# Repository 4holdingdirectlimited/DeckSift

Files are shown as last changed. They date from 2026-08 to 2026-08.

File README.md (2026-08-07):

# DeckSift

A TCG card scanner and physical sorter that runs **entirely on your own machine** — no hosted services, no logins, no cloud. A webcam identifies cards via on-device AI embeddings, a rule engine decides which bin each card belongs in, and an Arduino-driven feeder and servo mechanism physically routes the card there.

DeckSift is a fork of [MAULT](https://mault.xyz) by [dishwasher-detergent](https://github.com/dishwasher-detergent/mault). The v1 machine's Fusion 3D design, build photos, and firmware base come from the original project (MIT — full credit in [Credits](#credits)); DeckSift adds a fully-local, single-user software stack, firmware hardening, and a revised print kit (`card_sorter_decksift.3mf` — same parts, organized for faster, more efficient printing).

**License:** free for personal use. Commercial use (selling DeckSift or building it into a product) requires a license from 4holdingdirectlimited — see [LICENSE](LICENSE). The MAULT-derived portions remain MIT. See [Credits](#credits).

## MakerWorld

Original hardware build: https://makerworld.com/en/models/3066180-tcg-card-sorting-machine#profileId-3451252

## How it works

1. A feeder mechanism (continuous-rotation servo + roller) pulls a card from the hopper into view of the webcam, into a fixed, per-camera-calibrated scan region (see the calibration screen)
2. The browser crops that region to a straightened card image (plain Canvas 2D, no computer vision needed, since the camera mounting and card size are fixed and calibrated ahead of time)
3. The image is sent to the server for embedding search (SigLIP, running locally on CPU or DirectML GPU)
4. PostgreSQL vector similarity search (pgvector) identifies the card
5. Configurable, per-collection bin rules — plus bundle, set-chase, wishlist, and value routing — decide which bin the card should go to
6. The web app sends a serial command to the Arduino, which drives the trapdoor/paddle/pusher servos to route the card into that bin

## Features

- **Fully local & offline** — Postgres, the API, the web app, the vision model, and card art all run on this machine. No accounts, no hosted database, no cloud calls at scan time. Only the one-time card-data sync needs the internet.
- **Live webcam scanning** with automatic card detection and identification; captures wait for the card to physically settle at the sensor before the shot is taken
- **Multi-TCG support**: pluggable card-search adapters per game — MTG/Scryfall, Yu-Gi-Oh!, Digimon, Gundam Card Game, Pokémon, Disney Lorcana, One Piece, Star Wars: Unlimited, Union Arena, Flesh and Blood, and Pokémon TCG Pocket (11 games) — each with its own field definitions driving sorting, filtering, and bin rules; a config-driven architecture makes adding more games a small, independent task (see `custom/TCGS_ROADMAP.md`)
- **Rule-based sort bins**, grouped by collection, with and/or rule trees across each game's own card fields (color, rarity, price, set, type line, mana value, …)
- **Value-based binning** — numeric price rules on every bin (`Price (USD) greater than 2` → reject bin, etc.), backed by live prices for MTG and Yu-Gi-Oh!
- **Bundle mode** — assemble fixed-composition bundles (e.g. 15 common / 15 uncommon / 5 rare / 5 mythic) with no duplicates, optional holo filtering, live running value, and pause-on-complete. Every run gets an inventory **SKU** (`MTG-40-001`), stores the full list of cards it contained, and can be exported as a CSV record
- **Set-chase mode** — route every card from a target set that you don't already own into a chase bin, automatically building set-complete piles
- **Wishlist routing** — specific cards (by id or name pattern) route to their own bin ahead of normal rules
- **Holo/foil detection** — two-frame scan light (firmware-controlled LED) + heuristic classifier, with a smart skip so matte cards only need one frame
- **Misprint / error-card flagging** — every scan shows a match-accuracy %; cards whose art differs noticeably from the catalog (shifted colors, extra features) get an amber "possible misprint" flag so valuable error cards don't sail through silently
- **Sound bin-full logic** — per-bin status vs physical capacity, per-bin Empty/reset, and pause-on-overflow so a bin can never silently overflow
- **Collection tools** — export everything scanned as CSV (including a **TCGplayer-compatible inventory CSV** for the seller portal), a duplicate report, a set-completeness view, and a card library browser with set/rarity filters
- **Digitize mode** — bulk-record a library without sorting: every scanned card is saved to the collection while cards route to the catch-all bin
- **Orientation tolerance** — cards fed upside-down are auto-rotated before matching, so alignment is relaxed
- **Card grid** sorting (by name, price, rarity, etc.) adapts automatically to whichever game a collection uses
- **Remote monitoring** — watch an in-progress scan session live from another device on your LAN
- **Discord notifications** (optional) for sorter errors/jams
- **Feeder, servo, camera, and scan-light diagnostics** — live calibration tools plus hardware tests from the browser, so servos and lights are verified before a run
- **In-app hardware build guide** (`/build`) with bill of materials, wiring diagrams, and assembly instructions

## Stack

| Layer | What | Version |
| --- | --- | --- |
| Web | React + Vite + React Router + Tailwind CSS + TanStack Query | React 19 · Vite 6 · Tailwind 4 |
| Server | Hono + Drizzle ORM + PostgreSQL (pgvector) | Hono 4 · Drizzle 0.45 · Postgres 18.4 |
| Vision | SigLIP base (patch16-512) via `@huggingface/transformers`, onnxruntime-node (CPU q8 or DirectML GPU fp32) | transformers 3.8 |
| Auth | **none** — fully-local single-user build, no logins | — |
| Hardware | ESP32-S3 (primary) or Arduino Uno R4 Minima via Web Serial (9600 baud) — the same sketch also builds for RP2040/Pico + STM32 (see `arduino/main/CONTROLLERS.md`), PCA9685 servo driver, IR sensors, scan-light LED | — |
| Monorepo | Turborepo + pnpm workspaces | pnpm 9 |

**Security posture (2026-08):** `pnpm audit` reports **0 critical** and **0
high-severity issues in the runtime dependency graph**. The one remaining
runtime-path flag is a React Router advisory that only affects **RSC mode**
(server actions) — this app is a classic client-rendered SPA, so it does not
apply; the fix is v8-only and upgrading would be a breaking change with no
benefit here. All other `pnpm audit` findings are transitive dependencies of
dev-only tooling (the `shadcn` CLI, `tsup`, ESLint) that is never shipped or
exposed. The app itself is local-only and unauthenticated by design — it is
not intended to be exposed to the public internet.

## Project structure

```
packages/
├── shared/   @magic-vault/shared - types, constants, evaluate-bin rule engine
├── server/   @magic-vault/server - Hono API, Drizzle schema/db, card-search adapters, sync jobs
└── web/      @magic-vault/web    - React SPA (scanner, bins, collections, library, admin, build guide)
arduino/      Firmware + build docs (arduino/main/main.ino, BUILD.md, SERIAL_PROTOCOL.md)
3d model/     Printable enclosure/module design (Fusion 360 + .3mf)
custom/       Our docs: CHANGES.md (all modifications), SETUP.md (local runbook), TCGS.md, PLAN.md, HARDWARE_V2.md, PRODUCT.md
drizzle/      Generated SQL migrations
scripts/      Local helpers: start-server.cmd, start-web.cmd, local-db.mjs, backup-db.mjs,
              arduino-compile.sh
              (+ packages/server/scripts: seed-local.ts, apply-bin-capacities.ts, import-cardset.ts, bench-vectorize.ts)
```

## Getting started

**Prerequisites:** Windows (or Linux/macOS with adjustments), [pnpm 9](https://pnpm.io), Node 20.6+ (the run scripts use `--env-file`), and a portable PostgreSQL + pgvector install (see below). The browser must support the [Web Serial API](https://developer.mozilla.org/en-US/docs/Web/API/Web_Serial_API) (Chrome/Edge) for hardware control.

```bash
pnpm install
cp .env.example .env   # then fill in DATABASE_URL etc.
```

### 1. Local PostgreSQL (no Docker/admin needed)

Download the portable PostgreSQL + pgvector bundle (user-space, no admin rights or services required):

```bash
curl -L -o postgres.zip \
  https://github.com/YukeonWayne/pg_pgvector_binary/releases/download/v18.4-pgvector0.8.3-win32-x64/postgres-18.4-pgvector-0.8.3-win32-x64.zip
```

Extract it to `<workspace>/.local/postgres` (the helper scripts look there —
`<workspace>` is the folder *containing* your clone, e.g. `C:\Users\you`
when you cloned to `C:\Users\you\decksift`; override with `DECKSIFT_LOCAL_DIR`
if you'd rather keep local state inside the repo), then initialize and start:

```bash
PGBIN="<workspace>/.local/postgres/win32-x64/bin"
"$PGBIN/initdb" -D "<workspace>/.local/postgres/data" -U postgres -A trust -E UTF8 --locale=C
# Start detached (Windows):
powershell -NoProfile -Command "Start-Process -FilePath '<workspace>\.local\postgres\win32-x64\bin\postgres.exe' -ArgumentList '\"-D\" \"<workspace>\.local\postgres\data\" \"-p\" \"5433\" \"-c\" \"listen_addresses=127.0.0.1\" \"-c\" \"shared_buffers=1GB\"' -WindowStyle Hidden"
```

(`node scripts/local-db.mjs start` replaces the manual Start-Process line once
Postgres is set up — it launches the server with the same settings.)

Create the database and apply the local bootstrap (creates the pgvector extension, the RLS role, and the `auth_is_org_member()` function). Run it **before** `db:migrate` and **again after**:

```bash
"$PGBIN/psql" -h 127.0.0.1 -p 5433 -U postgres -c "CREATE DATABASE mault;"
"$PGBIN/psql" -h 127.0.0.1 -p 5433 -U postgres -d mault -f packages/server/sql/local-bootstrap.sql
pnpm --filter @magic-vault/server db:migrate
"$PGBIN/psql" -h 127.0.0.1 -p 5433 -U postgres -d mault -f packages/server/sql/local-bootstrap.sql
```

Then point `.env` at it:

```
DATABASE_URL=postgres://postgres@127.0.0.1:5433/mault
VECTORIZE_DEVICE=dml    # or cpu (see .env.example)
```

A helper script manages the server day-to-day, and can register a no-admin logon auto-start:

```bash
node scripts/local-db.mjs start|stop|status|install|uninstall
```

Back up the database with one command (safety net — see `scripts/backup-db.mjs`):

```bash
node scripts/backup-db.mjs backup        # dump to .local/backups
node scripts/backup-db.mjs list          # list existing backups
node scripts/backup-db.mjs restore <file>  # restore (wipes current data)
```

### 2. Seed + run

```bash
# One-time seed: games, default collection, bin set, default bundle config
cd packages/server && npx tsx --env-file ../../.env scripts/seed-local.ts

# Start the stack (two detached processes) — from the repo root:
powershell Start-Process -FilePath ".\scripts\start-server.cmd" -WindowStyle Hidden
powershell Start-Process -FilePath ".\scripts\start-web.cmd" -WindowStyle Hidden
```

Open **https://decksift.local:5173** (preferred) or **http://localhost:5173** — no login, it opens straight to the scanner.

**decksift.local** is the friendly hostname: run `node scripts/ssl-setup.mjs`
once to generate a locally-trusted HTTPS certificate (required because Web
Serial only works in a secure context), then add this line to your hosts file
(as admin):

```
127.0.0.1  decksift.local
```

Restart the web server afterwards. `localhost` keeps working as a fallback,
and the app is also reachable from other devices on your LAN via `http://<pc-ip>:5173`.

### 3. Card sync (the one internet step)

In the web app, go to **Admin → Sync** and run the sync for each game you'll use. The first MTG sync downloads the Scryfall catalog (~54k cards) and embeds each with the local SigLIP model — roughly 9–10 hours on a mid-range GPU, one-time and resumable (it skips cards already embedded, and the catalog is cached on disk). Syncs are queued one game at a time and auto-advance; the sync paces itself so your desktop stays responsive and scans keep priority.

> Until sync completes for a game, scanning can't match anything — the `cards` table is empty and the search has nothing to compare against.

### 4. Flash the firmware + calibrate

1. Flash `arduino/main/main.ino` — the **ESP32-S3 is the primary board**
   (native-USB Web Serial, optional Wi-Fi/WebSocket/OTA). Libraries:
   **ArduinoJson**, **Adafruit PWM Servo Driver**, and **WebSockets** (ESP32
   build only). See `arduino/main/WIRING_S3.md` for the DevKitC-1 wiring and
   `arduino/main/README.md` for the Tools-menu settings (Uno R4 / RP2040 /
   STM32 equivalents in `arduino/main/CONTROLLERS.md`).
2. Open **http://localhost:5173**, connect the board via **Web Serial**, then
   calibrate at `/app/calibrate` (drag the scan region, tune servo positions)
   and run the hardware diagnostics to verify servos and the scan light.
3. Load cards, connect the camera (see [Webcam](#webcam)), and scan.

**Full walkthrough, hardware BOM, wiring, and tuning:** see `custom/SETUP.md` (our local runbook) and `arduino/main/BUILD.md`.

## Environment variables

Copy `.env.example` to `.env` and fill in. All variables live in a single root `.env` (Vite reads up from `packages/web`).

| Variable | Purpose | Default |
| --- | --- | --- |
| `DATABASE_URL` | Local Postgres connection string | `postgres://postgres@127.0.0.1:5433/mault` |
| `PORT` | API port | `3001` |
| `WEB_URL` | CORS origin / absolute links (Discord) | `http://localhost:5173` |
| `VITE_API_URL` | Base URL of the API (baked into the web bundle). **Leave empty** for same-origin — the Vite dev/preview server proxies `/api` to the API, so any hostname (localhost, decksift.local, LAN IP) works | *(empty — relative)* |
| `VITE_APP_ENV` | `local` / `development` / `qa` (banner + warnings) | `local` |
| `VECTORIZE_DEVICE` | `cpu` (q8) or `dml` (DirectML GPU, fp32 — ~1.9× faster) | `cpu` |
| `SYNC_FETCH_BATCH` | Parallel image fetches during sync | `16` |
| `SYNC_EMBED_BATCH` | GPU embedding batch (8 is proven stable on weaker GPUs) | `8` |
| `SYNC_PACE_SCAN_MS` | Sync back-off per batch while a scan is active | `200` |
| `SYNC_PACE_IDLE_MS` | Sync beat per batch when idle | `10` |
| `ART_CACHE_DIR` / `SYNC_CACHE_DIR` | Override local cache locations | `<repo>/packages/server/.cache/…` |

## Database

Migrations live in `drizzle/`:

```bash
pnpm --filter @magic-vault/server db:generate  # generate a migration from schema changes
pnpm --filter @magic-vault/server db:migrate   # apply migrations
pnpm --filter @magic-vault/server db:push      # push schema directly (dev)
pnpm --filter @magic-vault/server db:studio    # open Drizzle Studio
```

The migration history is a single regenerated baseline from the current schema — all tables use org-scoped RLS policies (defense-in-depth for any future deployment; the local build enforces isolation at the route layer). Postgres starts with `shared_buffers=1GB` so the card catalog + vector index stay resident in RAM.

### What still needs the internet

- **Card data sync** (Scryfall / Yu-Gi-Oh! / Digimon / Gundam / Pokémon) in the Admin page — how the card database gets built
- **Card art** — the image proxy fetches new art; everything synced is disk-cached locally afterwards
- **One-time SigLIP model download** — the vision model downloads once from HuggingFace, then all scanning runs fully on-device
- **Discord webhooks** — optional, only if you configure a URL

Everything else — scanning, sorting, calibration, the database, and vision — runs entirely on the local machine.

## Hardware

The full bill of materials, wiring diagrams, and assembly instructions live in the app at `/build`. In short:

- **Controller** — ESP32-S3 (DeckSift's primary: native-USB Web Serial, more headroom) or the original Arduino Uno R4 Minima, both driving a PCA9685 servo controller over I2C. The same firmware builds for RP2040/Pico and STM32 — see [arduino/main/CONTROLLERS.md](arduino/main/CONTROLLERS.md) for per-board wiring, logic levels, and support status.
- 9 positional SG90 servos (3 per module: trapdoor, paddle gate, pusher) plus 1 continuous-rotation SG90 for the feeder
- IR sensors for card-feed detection (hopper + one per module)
- **Scan light** (LED 1, PCA9685 channel 0) — a small angled LED the firmware toggles for two-frame holo detection
- External 5 V PSU (4–10 A) into the PCA9685 `V+`, common ground with the controller (mandatory)
- Enclosure and module parts are in `3d model/` (Fusion 360 source + printable `.3mf`)

Upload `arduino/main/main.ino` (libraries: ArduinoJson, Adafruit PWM Servo Driver, WebSockets for the ESP32 build). It communicates via JSON over USB serial (9600 baud): the web app sends `{"bin": N}` and the Arduino runs the routing sequence. Protocol details in `arduino/main/SERIAL_PROTOCOL.md`.

## Webcam

Primary: **EMEET C60E 4K** — the higher resolution gives holo detection and the embeddings more detail to work with. Recommended settings:

- Autofocus: Off (fixed focus on the scan plane)
- Resolution: 1080p or 4K, whichever the scan-region calibration covers
- Brightness / contrast / saturation: moderate, consistent lighting

The original build used a Logitech C920 (Auto Focus: Off · Focus: 50% · Auto Exposure: On · Low Light Compensation: On · Auto White Balance: On · Brightness: 140 · Contrast: 140 · Saturation: 160 · Sharpness: 130).

## Documentation

- `custom/SETUP.md` — **the local runbook**: stack URLs, start/stop, first-run setup, bundle/chase/wishlist modes, bin capacities, value sorting, machine responsiveness tuning
- `custom/CHANGES.md` — every modification relative to upstream, in revert order
- `custom/TCGS.md` — multi-TCG architecture, top-20 TCG data-source status, adding a new game
- `custom/PLAN.md` — firmware roadmap (non-blocking state machine, pipelining, watchdog) and the machine-build commissioning checklist
- `arduino/main/BUILD.md` — hardware build guide, wiring, calibration
- `arduino/main/SERIAL_PROTOCOL.md` — JSON serial contract

## Credits

**Original machine design — MAULT by dishwasher-detergent (Kenneth Bass).** The
v1 card sorter's Fusion 3D design (`3d model/Card Sorter.f3d` / `card_sorter.3mf`),
the build photos, the parts list, and the Arduino firmware base all come from the
original [MAULT](https://mault.xyz) project, released under the MIT License. The
original is the sorter we built from, and it stays credited in the app footers,
the `/build` guide, and this file.

**3D model files** (`3d model/`) are licensed separately under
**CC BY-NC-SA 4.0** by Kenneth Bass — see `3d model/LICENSE`. The software in
this repository is licensed under the DeckSift License (personal use free,
commercial by license).

**DeckSift work — 4holdingdirectlimited.** Everything else: the fully-local
software stack (no hosted services, no logins, on-device vision, local card
storage), the firmware modifications (command-id correlation, jam detection,
watchdog timing, EEPROM calibration, scan light), and the revised print kit
(`3d model/card_sorter_decksift.3mf` — same machine, organized for faster,
more efficient printing). The full change log is in `custom/CHANGES.md`.

**License.** DeckSift is free for personal use; commercial use is by license from
4holdingdirectlimited (see [LICENSE](LICENSE)). The MAULT-derived portions
remain MIT-licensed under the original notice included in the LICENSE file.

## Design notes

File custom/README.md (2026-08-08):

# Custom

This folder is the home for **our** modifications to DeckSift — everything
that makes this build different from the upstream MAULT project. The upstream
project is tracked as the `upstream` git remote (`dishwasher-detergent/mault`);
all of our work lives on the `custom` branch (the repo default).

## How this project is organized

```
custom/                  <- this folder: our docs (CHANGES, SETUP, TCGS, PLAN)
arduino/main/main.ino    <- the firmware we modify IN PLACE (tracked by git on `custom`)
arduino/main/*.md        <- build/setup docs (also ours, tracked on `custom`)
```

**Important:** do not keep a second copy of `main.ino` in here. The firmware is
edited in place at `arduino/main/main.ino` — git on the `custom` branch is the
change tracker. This folder is for documentation and anything that doesn't
belong next to the sketch.

## Docs in this folder

| File | What it is |
| --- | --- |
| `CHANGES.md` | **Every modification vs upstream**, cumulative, in revert order (currently items 1–73) |
| `SETUP.md` | The local runbook: stack URLs, start/stop, first-run setup, bundle/chase/wishlist modes, bin capacities, value sorting, sync pacing |
| `TCGS.md` | Multi-TCG architecture, top-20 TCG data-source status, adding a new game |
| `PLAN.md` | Firmware roadmap (state machine, pipelining, watchdogs) + machine-build commissioning checklist |
| `HARDWARE_V2.md` | Production-leaning hardware review: materials/manufacturing, stability/mass, mechanism hardening, and the 3-machine/1-PC multi-machine plan |
| `PRODUCT.md` | Product strategy (v1 home → v2 commercial), adoption drivers, and the value-vs-effort feature backlog |

## Git workflow

- `custom` — the only active branch (also the GitHub default). All DeckSift
  work lives here.
- `upstream` — a read-only remote pointing at `dishwasher-detergent/mault`;
  `git fetch upstream` then `git merge upstream/master` (or selective
  file-level integration — see `CHANGES.md` Item 50) brings in anything new.
- **Keeping the fork banner tidy:** when GitHub shows "N commits behind"
  (upstream advanced), record their history without adopting their code:
  `git merge -s ours upstream/master -m "Sync with upstream history"` then
  push. Behind drops to 0; none of upstream's file content changes (their
  useful changes are still integrated selectively per `CHANGES.md`).
- There is no `master` branch in this repo — the pre-rename work line that
  briefly lived there was fully superseded by `custom` and deleted.

## Status

All modifications are documented in `CHANGES.md` (items 1–73). The headline
deliverables, all on the `custom` branch:

- **Fully local, no logins** — removed hosted Neon, Supabase-style auth, and
  better-auth; single-user local build with a portable local PostgreSQL
  (item 12–13)
- **Local-first everything** — disk-cached card art + sync catalogs (item 14,
  37), local card hydration (item 15), on-device SigLIP with optional DirectML
  GPU acceleration (item 16)
- **Multi-TCG** — config-driven adapters for MTG, Yu-Gi-Oh!, Digimon, Gundam,
  Pokémon + dataset importer for no-API games (item 19–20, 23, 27)
- **Seller/collector features** — value-based binning (21), bundle mode with
  holo/duplicate toggles + value (24, 29, 31), per-bin capacity + bin status
  (7, 30), set-chase mode (35), wishlist routing (36), export CSV / duplicates /
  set completeness (32–34)
- **Holo detection** — two-frame scan light + heuristic classifier (17–18),
  needs threshold calibration on the real rig (`PLAN.md`)
- **Firmware** — command-id ACK correlation, jam detection on all modules,
  boot recovery, EEPROM calibration persistence, stage-1 watchdog
  (1, 4–6, 10); full non-blocking state machine + interrupt-driven IR
  feeding delivered (49); pipeline feed (start next card while the
  previous one is still routing) still planned (`PLAN.md`)
- **Tooling & CI** — typecheck, firmware compile, CI checks (2)

Machine-specific operational details live in `SETUP.md`.

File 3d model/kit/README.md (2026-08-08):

# DeckSift Bambu Lab print kit

A quantity kit for the printable side of the machine, organized for faster,
more efficient Bambu Studio print batches (fewer color/material changes,
better bed utilization). The geometry is **identical** to the original parts —
this kit only reorganizes them.

## Files

| File | What it is |
| --- | --- |
| `QUANTITY_SHEET.md` | One machine's printable parts as a tick-box checklist, with filament/settings notes |
| `PLATES.md` | The 16-plate print plan for `card_sorter_decksift.3mf` |

## The 3MFs

- `3d model/card_sorter.3mf` — the original design (dishwasher-detergent),
  mesh, slicer-ready.
- `3d model/card_sorter_decksift.3mf` — DeckSift's revised parts file,
  print-optimized: **30 unique objects across 16 plates** (plate previews are
  embedded as `Metadata/plate_N.png`). Use this one with this kit.

Both files are the same machine — pick whichever matches your print setup.
3D files are CC BY-NC-SA 4.0 (`3d model/LICENSE`); full credit to the
original designer (see repo README Credits).

## Workflow

1. Open `card_sorter_decksift.3mf` in Bambu Studio.
2. Walk the 16 plates in order; tick the functional groups in
   `QUANTITY_SHEET.md` as you print.
3. Assemble per `arduino/main/BUILD.md` (structural → servos → sensors →
   wiring → firmware → calibrate).

## Notes

- The 3MF objects are unnamed meshes — the sheet groups parts by machine
  role, so keep the plate preview open while printing.
- PLA for housings; PETG if warm. 0.2 mm layers, 15–20 % infill (solid where
  the preview shows pads).

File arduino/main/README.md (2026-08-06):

# DeckSift — Arduino firmware & build docs (`arduino/main`)

This folder contains the firmware and build documentation for the **DeckSift TCG card sorter** — a hopper-fed, Arduino-driven machine that physically routes scanned trading cards into one of seven bins.

| File | Purpose |
| --- | --- |
| `main.ino` | The firmware — **one universal sketch** that runs on several boards (see below). |
| `board-config.h` | Board abstraction: EEPROM init/commit, I2C pins, interrupt attach, IR pin defaults. |
| `BOM.txt` | **Printable shopping list** — every part, screw, and tool with quantities. |
| `CONTROLLERS.md` | Per-board wiring, logic levels, power, and honest support status. |
| `WIRING_S3.md` | **Pin-by-pin ESP32-S3 DevKitC-1 wiring guide** (header layout, PCA9685, IR, LEDs, power). |
| `BUILD.md` | Complete build guide: bill of materials, wiring, assembly, first power-on, calibration. |
| `SERIAL_PROTOCOL.md` | JSON command/response reference for talking to the firmware over USB serial (and Wi-Fi). |

> Upstream source (the machine's original design): [github.com/dishwasher-detergent/mault](https://github.com/dishwasher-detergent/mault) · interactive build guide: [mault.xyz/build](https://mault.xyz/build) · 3D models: `3d model/Card Sorter.f3d` (Fusion 360) and `3d model/card_sorter.3mf` (slicer-ready) in the upstream repo. The firmware here is DeckSift's modified version of that base.

## What the machine does

A hopper feeds cards one at a time through three stacked routing modules. Each module can drop a card into one of two side bins (via a paddle gate and pusher) or pass it down to the next module (via a bottom trapdoor). Bin 7 is a catch-all with all three trapdoors open:

| Module | Bins |
| --- | --- |
| Module 1 | Bin 1, Bin 2 |
| Module 2 | Bin 3, Bin 4 |
| Module 3 | Bin 5, Bin 6 |
| (catch-all) | Bin 7 |

Each module has **3 positional SG90 servos** (bottom trapdoor, paddle gate, pusher) plus an **IR sensor**; a **continuous-rotation SG90** runs the feeder. All servos are driven by one **PCA9685** over I²C. The web app sends `{"bin": N}` over USB serial and the Arduino runs the full routing sequence.

## Supported boards (universal firmware)

One sketch, several controllers — `board-config.h` hides the small
differences (EEPROM emulation, I2C pins, interrupt attach), so you just pick
the board in the Arduino IDE / PlatformIO and flash:

| Board | Status | Notes |
| --- | --- | --- |
| **ESP32-S3** | ✅ Compiles + flashing docs; ⚠️ wiring not yet commissioned | DeckSift's primary going forward. Flashing settings below; wiring/power/logic-level guide in `CONTROLLERS.md`. |
| **Arduino Uno R4 Minima** | ✅ Reference build (compiles + wired) | The original controller; real EEPROM. |
| **RP2040 / Pico** | ✅ Compiles (3 % flash); ❌ not commissioned | Flash-emulated EEPROM (`EEPROM.begin`). See `CONTROLLERS.md` before wiring. |
| **STM32** | ✅ Compiles (GenF4); ❌ not commissioned | Flash-emulated EEPROM. See `CONTROLLERS.md` before wiring. |
| **Classic Uno/Nano** | ⚠️ Too little RAM | Sketch needs ~6 KB SRAM; the ATmega328P has 2 KB. |

> ⚠️ **Compiling ≠ supported.** Until a board has been wired and fully
> calibrated, treat it as experimental — the sketch is portable, but the
> machine wiring is only proven on the Uno R4. Read **`CONTROLLERS.md`**
> (logic levels, pins, power) before building a non-Uno machine.

## Flashing the firmware

1. Install the **Arduino IDE** (or arduino-cli).
2. Install the required libraries via **Library Manager**:
   - **ArduinoJson**
   - **Adafruit PWM Servo Driver** (also pulls in Adafruit BusIO)
   - **WebSockets** (only needed to compile the ESP32 build — used for the
     Wi-Fi/WebSocket transport + OTA; other boards ignore it)
3. Select your board + COM port (settings below), open and upload `main.ino`.
4. Open the **Serial Monitor at 9600 baud** — after the board resets you should see:

   ```json
   {"status":"ready"}
   ```

5. In the web app, connect the controller via **Web Serial**, then calibrate at `/app/calibrate` (see `BUILD.md` → Calibrate from the app).

### ESP32-S3 — recommended Tools menu settings

Web Serial needs the board to expose a serial port the browser can see. The
correct setting depends on which of the two USB paths your board has:

| Board type | USB CDC On Boot | Upload Mode | Notes |
| --- | --- | --- | --- |
| **With a USB-serial bridge (CH340/CH343/CP2102) — the common dev board** | **Disabled (default)** | **UART0 / Hardware CDC (default)** | `Serial` maps to UART0 through the bridge; flash and Web Serial both use that port. This is what was verified on a CH343 dev board. |
| **Native USB only** (no bridge chip) | **Enabled** | UART0 / Hardware CDC | `Serial` maps to the native USB port. |

Other recommended settings for both:

| Setting | Value | Why |
| --- | --- | --- |
| Board | **ESP32S3 Dev Module** | Generic S3 board |
| Flash Size | **16 MB** (if your module has it) or **8 MB** | Match your module — the 4 MB default scheme already has dual 1.25 MB OTA app slots, so extra flash only buys bigger SPIFFS, not OTA headroom |
| Partition Scheme | **Default 4 MB with spiffs** | The ESP32 build is ~1 MB (76% of the 1.25 MB app slot) — keep a scheme with **dual OTA slots** (this one is OTA-verified). Avoid "no OTA"/minimal schemes |
| CPU Frequency | **240 MHz** | Default |
| I2C pins | GPIO **8** (SDA) / **9** (SCL) | PCA9685 bus — override with `-DI2C_SDA=n` if your wiring differs |
| Upload Speed | **921600** | Faster flashing |

Equivalent `platformio.ini` (PlatformIO — drop the `USB_CDC_ON_BOOT` flag on
a bridge-equipped board, keep it for native-USB-only boards):

```ini
[env:esp32s3]
platform = espressif32
board = esp32-s3-devkitc-1
framework = arduino
build_flags =
  ; -DARDUINO_USB_CDC_ON_BOOT=1   # only for native-USB-only boards
  -DI2C_SDA=8
  -DI2C_SCL=9
monitor_speed = 9600
```

> Uno R4 / RP2040 / STM32 need no special settings — Web Serial works via
their built-in USB serial.

### ESP32-S3 — Wi-Fi, WebSocket & OTA (optional)

The ESP32 build can join your Wi-Fi network so the browser talks to the board
over the LAN and the Arduino IDE pushes updates over the network:

1. Flash the firmware over USB as above, then connect in the web app
   (**Connect Device**) and open **Calibrate → Wi-Fi & OTA**.
2. Enter your network SSID + password and hit **Save & Connect**. The board
   stores them in EEPROM and joins the network; it announces its IP
   (`{"status":"wifi","ip":…}`) which the panel auto-fills.
3. Click **Connect** next to the board address — the browser now drives the
   machine over Wi-Fi (`ws://decksift-board.local:81`), so the USB data cable
   can be unplugged (keep USB for power, or power from the 5 V PSU rail).
4. OTA: in the Arduino IDE, select the board's network port
   (**Sketch → Upload Using a Network Port**). The orange comms LED lights
   while a network flash runs.

> **arduino-cli on Windows:** `arduino-cli upload -p <ip> …` fails with
> “No response from device” until you allow `espota.exe` through Windows
> Firewall (inbound TCP — the device connects back to the tool mid-flash).
> The Arduino IDE already has this rule; run once as admin:
> `New-NetFirewallRule -DisplayName "ESP32 OTA (espota)" -Direction Inbound -Action Allow -Program "$env:LOCALAPPDATA\Arduino15\packages\esp32\hardware\esp32\<core>\tools\espota.exe" -Profile Any`

Multi-rig setups: change `WIFI_HOSTNAME` in `main.ino` per board (e.g.
`decksift-board-2`) so they don't collide on mDNS. See `SERIAL_PROTOCOL.md`
for the Wi-Fi commands.

## Quick test after first power-on

With the external servo supply connected, send over serial:

```json
{"test": true}
```

This cycles every bottom and paddle open, sweeps all pushers left then right, resets to neutral, briefly spins the feeder, and replies `{"status":"test_complete"}`.

## Pin and channel summary (full details in `BUILD.md`)

- **IR sensors** (active-LOW, internal pull-up): Module 1 gate → `D2`, Module 2 gate → `D3`, Module 3 gate → `D4`, Hopper throat → `D5`
- **PCA9685** I²C to Arduino `SDA`/`SCL`, logic `VCC` → `5V`, `GND` → `GND`
- **PCA9685 channels**: `0` = LED 1 (scan light), `1` = LED 2 (green, operating), `2` = LED 3 (red, fault), `3` = LED 4 (orange, comms fault), `4–6` = Module 1 (bottom, paddle, pusher), `7–9` = Module 2, `10–12` = Module 3, `13` = Feeder, `14–15` spare
- **Servo power**: external 5 V PSU (4–10 A) into PCA9685 `V+`, with the PSU ground tied to **both** PCA9685 `GND` and Arduino `GND` (common ground is mandatory)

## Webcam

Primary: **EMEET C60E 4K** — the higher resolution gives holo detection and
the embeddings more detail to work with. Recommended: autofocus off (fixed
focus on the scan plane), 1080p or 4K capture, moderate and consistent
lighting.

The original build used a Logitech C920 (Auto Focus: Off · Focus: 50% · Auto
Exposure: On · Low Light Compensation: On · Auto White Balance: On ·
Brightness: 140 · Contrast: 140 · Saturation: 160 · Sharpness: 130).

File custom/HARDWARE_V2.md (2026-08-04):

# Hardware v2 — production-leaning review & multi-machine plan

This document reviews the physical sorter as it stands and lays out a v2 path
toward **small-scale production**: a sturdier, faster, more reliable machine,
and — long term — running **three machines + three cameras off one computer**,
concurrently, instead of building one bigger machine.

Current machine (v1) baseline, from `arduino/main/BUILD.md`:

- 3 stacked routing modules × 3 **SG90** servos (trapdoor, paddle, pusher) + 1
  continuous-rotation SG90 feeder — all on one PCA9685
- 4 reflective IR sensors (hopper throat + one per module gate), polled in
  firmware
- PLA/PETG printed structure, M2/M3 screws into plastic, 5 V 4–10 A PSU
- Routing delays: card-enter 300 ms · paddle 300 ms · push 600 ms (~3 s/card)

Companion docs: `PLAN.md` (firmware roadmap — non-blocking state machine,
interrupt feeding, watchdogs, the v2 servo/detection notes) and this page's
"Software" section for multi-machine support.

---

## 1. Material & manufacturing — from one-off prints to production

### 1.1 Material choice per part

PLA is fine for a hobby prototype but wrong for production: it creeps under
constant servo load, softens in a warm room (a card sorter near a window or a
laptop exhaust is plenty), and is brittle at the thin bosses around servo
screws. What to use instead:

| Material | Creep | Heat | Toughness | Print ease | Verdict for us |
| --- | --- | --- | --- | --- | --- |
| PLA | poor | poor (~55 °C) | brittle | easiest | keep for prototype only |
| PETG | ok | ok (~80 °C) | good | easy (no enclosure needed) | **minimum viable production material** |
| ABS | ok | good (~100 °C) | good | needs enclosed printer + fumes | good for housings; overkill on ease |
| ASA | ok | good | good | like ABS, UV-stable | best drop-in for ABS without the UV worry |
| Nylon / PA-CF | great | great | very tough | hard (drying, warping) | only for wear parts / arms |
| Injection mold | best | — | — | one-time tooling cost | the real production step (see 1.3) |

**Recommended v2 material map:**
- **Module housings + base:** ASA (or PETG if no enclosed printer). ASA prints
  like ABS, resists heat/creep/UV, and stays dimensionally stable under servo
  loads.
- **Pusher arms, flapper linkages, feeder roller core:** PETG or nylon — these
  take the most force.
- **Bearing/shaft bosses:** design in seats for brass heat-set inserts and
  press-fit bearings rather than printing the hole itself (see §3).
- **Print settings for production parts:** ≥4 perimeters, ≥40 % infill
  (gyroid), 0.2 mm layer height, **anneal PETG/ASA** after printing (bed- or
  oven-based) to relieve layer stress and improve interlayer strength.

### 1.2 Fasteners & assembly quality

The v1 BOM is 22× M3 + 33× M2 self-tapping into plastic. That's the classic
field-failure point — screws strip on the second rebuild.

- **Heat-set brass inserts (M2/M3)** in every screw boss the firmware touches
  (servo mounts, module stacking, base panels). Machines get torn down for
  calibration/jams; threaded inserts survive it.
- **Thread-locker** (blue Loctite) on servo-horn screws and any M3 that holds
  a moving part.
- **Cable management as a first-class feature:** a v2 base has a cable
  channel per module and a single connector (e.g. 2× IDC or a small
  Molex/Phoenix connector) per module so a module can be swapped in the field
  without re-wiring 10 servos. This is the difference between "one-off" and
  "serviceable in production".

### 1.3 Real production: injection molding

If we ever run, say, 10+ units, the **module housing is the part to mold**
(one housing × 3 per machine = high volume, moderately complex, consistent
dimensions beat every printed part). The base plate can stay laser-cut sheet
metal. Rule of thumb: injection molding starts to win when you need ≥ several
hundred of a part and the design is frozen. Until then, ASA/PETG printing +
brass inserts is the pragmatic step.

---

## 2. Stability & mass — the free throughput upgrade

A light PLA machine **shakes** at the moment a servo slams a pusher across.
That vibration does three bad things at higher speed: IR sensors get false
edges, the camera image blurs/rolls during the capture window, and card
settling takes longer because the stack is still ringing. A stable base fixes
all three — it's the cheapest way to shorten `DELAY_*` times.

**v2 stability plan:**
- **Mass under the machine, not on it:** a 6 mm laser-cut steel base plate
  (≈300×300 mm ≈ **4 kg**) or a paving-slab/plywood sandwich bolted to the
  printed base. Target ≥3–4 kg of dead weight below the modules.
- **Sorbothane / soft-silicone feet** (not hard rubber) under the plate, sized
  for the mass — decouples the machine from the desk and damps servo
  transients. Hard feet just pass the vibration through.
- **One rigid spine:** bolt the 3 modules to a single aluminum backplate
  (3–4 mm) instead of stacking each module on the plastic of the one below.
  Eliminates cumulative flex, keeps the card path straight, and keeps the
  camera mount rigid.
- **Lower the center of gravity:** put the PSU and Arduino under the base
  plate, not beside the machine.
- **Camera mount on the machine, not the desk:** a rigid arm off the
  backplate keeps the scan region fixed relative to the card plane; vibration
  is then common-mode (card and camera move together) and the capture stays
  sharp.

**Result:** with the mass + damping in place, `DELAY_CARD_ENTER` and the
settle times can be measured and shortened safely — the machine stops shaking
before the card does.

---

## 3. Mechanism hardening (the parts that wear)

- **Servos → MG90S** (metal gears, ~2.2 kg·cm): survives sustained pushing,
  pin-compatible (see `PLAN.md` v2 section for current draw/capacitance
  notes). For the pusher specifically, consider a metal-gear **MG996R**-class
  servo if the arm needs more authority — only where measured torque demands
  it, since they draw ~1 A each.
- **Bearings, not plastic-on-plastic:** the paddle linkage and pusher arm
  pivot on printed holes today. v2 seats **brass bushings or 623/624
  ball bearings** in those pivots. Result: consistent motion, no
  print-tolerance binding, and no hole-wear over thousands of cycles.
- **Metal pin through the flappers:** the shared paddle linkage is a
  screw-in-plastic joint; v2 uses a steel dowel pin + bearings so both
  flappers track evenly for the machine's lifetime.
- **Feeder (the real throughput bottleneck):** the G20 o-ring roller works but
  slips and double-feeds on glossy cards.
  - v2: a **silicone pinch roller** with an adjustable gap (two rollers, one
    driven) — precise single-card separation, better on foils.
  - Add a small **hopper agitator** (a servo wiggle or vibrator) so cards
    don't bridge at the throat.
  - An **encoder on the feeder** (slotted wheel + IR pair) measures feed
    distance — stop position becomes sensor-confirmed, and a second card
    feeding is detectable (encoder keeps moving while the beam is still
    broken).
- **Card path:** radiused guides, anti-static brushes at the hopper (foil
  cards + dry air = static cling), and a replaceable wear strip where the
  pusher face contacts cards.

### Sleeve tolerance (v2 design decision)

v2 should sort **sleeved cards** (a store's inventory lives in sleeves; Roca's
Sifter already reads them). Every tolerance that currently assumes a bare
0.3 mm card needs a sleeved variant:

- **Bin capacity halves:** a premium sleeve ≈ 0.4 mm + the 0.3 mm card ≈
  **0.7 mm** total. The shared constants now expose
  `CARD_THICKNESS_SLEEVED_MM = 0.7` / `computeBinCapacity(bin, thickness)`, so
the app can flip capacities without new code — the machine must physically
accept ~half the cards per bin (or the bins get deeper).
- **Feed path:** feeder gap, pinch-roller spacing, hopper throat and guide
  widths all open up ~0.4 mm; the o-ring/silicone roller contact patch needs
  to grip the sleeve without slipping (sleeves are slicker than card stock).
- **Module clearances:** card-path height and the trapdoor/paddle gaps must
  pass a sleeved card (bulkier, slightly stiffer).
- **IR detection:** sleeve gloss can double-reflect the beam; re-aim or
  dim the sensors (a comparator front-end helps — see PLAN.md).
- **Foil detection on sleeved cards:** the sleeve is glossy and adds its own
  reflections, so the two-frame holo difference signal needs recalibration
  (light angle, thresholds) against real sleeved captures — this is
  calibration work on the rig, not a code change.
- **Orientation:** sleeved cards feed the same way; the orientation-tolerant
  crop (implemented in the web app) is sleeve-agnostic.

Software is already ready: `computeBinCapacity(bin, thickness)` + the
sleeved constant mean the capacity model switches with one value; the
remaining work is mechanical (gaps) and calibration (foil thresholds).
- **Card path:** radiused guides, anti-static brushes at the hopper (foil
  cards + dry air = static cling), and a replaceable wear strip where the
  pusher face contacts cards.

---

## 4. Sensing & control for production reliability

Recap + production additions on top of `PLAN.md`:

1. **Interrupt-driven IR edges** (both `PLAN.md` and v2) — no polling, no
   missed edges; lets the feeder run continuously.
2. **Comparator front-end** (LM393) on the IR sensors — clean digital edges,
   immune to the sensor's analog transition zone.
3. **Confirm motion by sensor, not timer** — every phase completes on an edge
   or a watchdog budget, never on a fixed blind delay. This is what makes
   "faster" also mean "safer".
4. **Jam/EOF feedback:** module gate sensors already exist; wire the hopper
   sensor to also flag "empty hopper" to the operator (it does today) and add
   a **card-confirmed-at-bin** check where cheap (a fifth sensor per module
   isn't needed — the gate sensor + pusher position is enough).
5. **E-stop + cover interlock** for unattended production runs — a hard stop
   that also tells the app "machine halted, clear me".

---

## 5. Multi-machine: 3 machines, 1 computer

Long-term goal: sync + run **three machines and three cameras off the same
PC**, concurrently, sharing one card library — instead of a bigger single
machine.

### 5.1 Physical / electrical

| Concern | v1 (1 machine) | v2 (3 machines) |
| --- | --- | --- |
| USB | 1× serial + 1× camera | **Powered USB 3 hub**; 3× serial (Web Serial supports multiple ports) + 3× cameras |
| Camera bandwidth | 4K single | 3× **1080p MJPEG** (~4K over USB on three UVC cameras saturates the bus and starves the GPU-adjacent pipelines). 1080p is ample for card ID + holo |
| Servo power | 1× 5 V 4–10 A | **Per-machine 5 V PSU** (fault isolation; one dead rail doesn't take down the farm). 30+ MG90S servos across 3 rails |
| Control | 1× Uno R4 | 1× Uno R4 per machine — each is a self-contained sorter brain; the PC is the orchestrator |
| Vision | 1× EMEET C60E | 1× camera per machine on a rigid arm; per-machine scan-region calibration |

### 5.2 Software architecture (the real work)

Today the app assumes one machine: a single serial provider, a single camera,
a single active bundle run, org-scoped bins/scans. Multi-machine needs a
**station** concept:

- **`station_id` on the machine-facing entities** — scans, bin status, bundle
  runs (bundle **configs stay shared**: all machines can run the same
  recipe). Physical bins are per-machine; the card library, collections, and
  rules are shared.
- **One server, per-station state:** scan uploads carry `stationId`; the
  routing pipeline (`use-scanned-cards.tsx`) becomes a per-station instance —
  3 serial providers, 3 cameras, 3 bin-status strips, 3 bundle runs. A
  station switcher in the UI (or a 3-column "farm" layout on one screen).
- **The GPU is the shared bottleneck — and it's fine:** one SigLIP session
  embeds serially at ~0.4 s/card (DirectML). 3 machines at 2 s/card need
  ~1.5 embeds/s — under the ~2.5/s the single model sustains, so one GPU
  serves all three. Embeddings just queue; the sync's scan-aware pacing
  already keeps the desktop usable.
- **DB:** add `station_id` to scans + bundle runs (nullable — single-machine
  installs unaffected). No new tables otherwise.
- **Networking:** everything stays local (USB), no changes to sync/library.

### 5.3 Throughput math

| Config | Per-card | Per machine / hr | Farm / hr | 8-h shift |
| --- | --- | --- | --- | --- |
| v1 (current) | ~3 s | ~1,200 | 3× = 3,600 | ~29k |
| v2 (interrupt feed + MG90S + pipelined) | ~1.7 s | ~2,100 | 3× = 6,300 | ~50k |
| v2 with shorter bins (3-bin configs) | ~1.4 s | ~2,500 | 3× = 7,500 | ~60k |

So a 3-machine v2 farm sorts a **100,000-card backlog in ~2 shifts** — that's
small-scale production territory (a local game store's bulk buy-in, a
collection liquidation, etc.) without a conveyor-belt machine.

---

## 7. vs commercial machines (the Roca question)

*“Could three upgraded units perform like a ~$25–30k Roca?”* — now we can
answer it with real numbers, because TCGplayer publishes the specs:

| Machine | Cost | Capacity | Throughput | Notes |
| --- | --- | --- | --- | --- |
| **Roca Sorter** | ~$25k | 1,000-card batch | **Sort 500/hr · Sift 725/hr** | Alphabetizes + digitizes; ~2 h per 1,000-card batch; over 50 programmed sorts; **Yu-Gi-Oh! needs a separate machine** (different card size) |
| Roca Sorter Max | ~$40k | 3,000-card run | Sort 300/hr · Sift 450/hr | Same, bigger batch |
| Roca Sifter | ~$2–3k | single/stream | **1,800/hr sift** | Compact add-on: reads cards **in premium sleeves**, separates foil/non-foil, any orientation; designed to feed the Sorter |

### The headline: we're already faster on raw sorting

| Config | Cards/hr (sort) | vs Roca Sorter |
| --- | --- | --- |
| Our v1 (current, ~3 s/card) | **~1,200** | **2.4×** |
| Our v2 (one machine, ~1.7 s/card) | **~2,100** | **4.2×** |
| Our 3× v2 farm | **~6,300** | **~12.6×** |

**So on raw “put these cards in those bins” throughput, one of our v1 machines
already beats the $25k Roca Sorter, and the farm is an order of magnitude
ahead.** Roca's price buys *other* capabilities, not speed. Where Roca genuinely
wins:

1. **Alphabetizing & full inventory ordering** — Roca sorts a batch into a
   complete, sell-ready order (we route to 7 bins).
2. **Digitization + TCGplayer integration** — every card read to a database
   and listable in one workflow (we record scans, but don't list).
3. **Sleeved-card handling** (Sifter) — reads cards *in premium sleeves*; we
   require unsleeved cards.
4. **Foil sifting at scale** — Sifter's foil separation is industry-proven; our
   holo detection is still in calibration.
5. **Unattended batch runs** — load 1,000, walk away for 2 h. Ours wants a
   hopper re-load and bin-empty roughly every ~500–1,500 cards.
6. **Orientation tolerance** — Roca reads cards in any orientation; our scan
   region expects a fixed orientation (feeder-straightened).
7. **Service/warranty + dedicated support.**

And where **we** win beyond cost:

- **One machine, all games** — Roca requires a *separate $25k unit* for YGO;
  our single unit handles MTG/YGO/Pokémon/Digimon/Gundam (and any added TCG)
  by changing the collection.
- **Cost:** ~$1k/machine → ~$3–5k for the 3-machine farm vs $25–75k of Roca
  hardware (Sorter + Max + Sifter + YGO unit).
- **No subscriptions or lock-in** — Roca sells a Software & Service Plan;
  ours is local and free forever.
- **Directed sorting tools Roca lacks:** bundle mode (Roca has “Pack Creator”,
  comparable), set-chase, wishlist routing, per-card value rules, per-bin
  capacity management.

### What to borrow from Roca (the “similar tools” worth copying)

- **Sleeve-tolerant feeding** — a feeder that handles sleeved cards would let
  us sort inventory without unsleeving. Big workflow win for a store.
- **Orientation-tolerant reading** — relax the scan-region constraint (or add
  a rotation-tolerant crop) so cards needn't be perfectly aligned.
- **Foil sift as a first-class mode** — a dedicated “foil / non-foil” sift
  pass (our two-frame holo detection, run as a pure sift) mirrors the Sifter.
- **Batch digitization** — a “digitize this hopper” mode that scans + records
  every card without sorting (feeds the library + collection DB).

### Honest verdict

For **bins, bundles, chase sets, and value/rule sorting**, three of our
machines beat a $25k Roca on throughput by ~10× and on cost by ~5–10×. What
Roca buys that we don't have is *complete inventory digitization +
alphabetization + sleeved-card handling + unattended autonomy* — those are
feature gaps, not speed gaps, and the top two (sleeve feed, digitize mode)
are on the v2 ideas list above.

### The measurement gate (do this before believing any of the above)

All of section 7 assumes the current machine is tuned and *measured*. Before
spending on v2/multi-machine:

1. Finish the v1 firmware (state machine + interrupt feeding — `PLAN.md`).
2. Run the first machine on real card stock and record **cards/hour, error
   rate, jams per 1,000 cards, and double-feed rate**. These four numbers are
   the baseline every upgrade is judged against (and the honest test of the
   1,200/hr claim above).
3. Try the cheapest upgrades first (stability base, feeder tweaks) and
   re-measure — only spend on MG90S/bearings/encoders where the baseline says
   the bottleneck actually is.
4. Only then decide the farm: the numbers will tell you if 3 machines buy you
   the Roca-class throughput at 1/10 the cost — or where the gaps make it not
   worth it for your actual workloads.

---

## 8. Phased roadmap (revised)

Priority order is deliberate: **software first, then tune the single machine,
measure it, and only then spend on v2/farm hardware.**

- **Phase 0 — finish v1 firmware + current software** (from `PLAN.md`):
  non-blocking state machine, interrupt feeding, watchdogs, plus any remaining
  app work. Nothing else happens until the first machine runs the whole
  scan → route → bin pipeline reliably.
- **Phase 1 — build + tune the first machine:** assemble it, calibrate,
  then run the **measurement gate** (§7): cards/hour, error rate, jams and
  double-feeds per 1,000. Fix what the numbers say is broken (feeder first —
  it is almost always the bottleneck). Re-measure after every change.
- **Phase 2 — cheap upgrades, measured:** stability base + sorbothane feet,
  feeder tweaks — the low-cost changes that shorten the blind routing delays.
  Re-measure. Only the bottlenecks that survive this get the expensive
  treatment (MG90S, bearings, comparator/encoder) in Phase 3.
- **Phase 3 — v2 prototype (one machine):** the hardened parts from §1–§4
  (ASA/PETG + brass inserts, bearings, pinch roller, encoder, comparator).
  Target **~1.7–2 s/card** sustained. Re-measure against the Phase 2 numbers;
  if the upgrade didn't move the metric, don't replicate it three times.
- **Phase 4 — station software:** `station_id` plumbing, per-station scanner
  islands, 3 serial + 3 cameras on one PC; verify one GPU serves 3 machines.
- **Phase 5 — the farm:** 3 machines running concurrently (build the third
  machine only if Phase 3's numbers justify it), injection-molded housings if
  volume is real, daily ops routine (hopper load, bin empty, per-machine CSV
  export).

Each phase is independently shippable; Phases 0, 2 and 4 are mostly software
or cheap, and every hardware decision is gated on a measured number rather
than enthusiasm.

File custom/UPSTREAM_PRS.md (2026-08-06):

# Upstream pull requests — status & ready-to-paste descriptions

Three firmware PRs back to the original project
(`dishwasher-detergent/mault`). All are **open, rebased onto the latest
upstream master, and MERGEABLE**. All three use **LED 1 (ch0) as the scan
light** — no spare-channel LED 5 wiring — and upstream's own master has since
moved to LED 1 too, so the PRs align with the maintainer's direction.

| PR | Branch | Status |
| --- | --- | --- |
| [#4](https://github.com/dishwasher-detergent/mault/pull/4) | `pr/fw-robustness` | OPEN · MERGEABLE |
| [#5](https://github.com/dishwasher-detergent/mault/pull/5) | `pr/fw-config` | OPEN · MERGEABLE · title updated to "scan light (LED 1)" |
| [#6](https://github.com/dishwasher-detergent/mault/pull/6) | `pr/fw-state-machine` | OPEN · MERGEABLE |

Each branch was rebased onto `upstream/master` (61c67e7) with our exact
firmware content, so each PR's diff is a clean reviewable change set.

The full PR bodies (for updates or re-opening) live in:

- `custom/upstream-pr-1.md` — PR #4 (fw-robustness)
- `custom/upstream-pr-2.md` — PR #5 (fw-config)
- `custom/upstream-pr-3.md` — PR #6 (fw-state-machine)

---

## PR 1 — `pr/fw-robustness`

Harden firmware: id-correlated replies, fixed serial buffer, all-module jam
watch, boot recovery. Body: `custom/upstream-pr-1.md`.

## PR 2 — `pr/fw-config`

Persist servo calibration to EEPROM and add a scan light (LED 1). Supersedes
the earlier "scan light (LED 5)" version — the scan light moved to LED 1/ch0
to keep the wiring on existing hardware. Body: `custom/upstream-pr-2.md`.

## PR 3 — `pr/fw-state-machine`

Rebuild firmware as a non-blocking state machine with interrupt-driven
feeding. Includes the robustness fixes and the config persistence + scan
light from the sibling PRs, so this branch is the complete modern firmware.
Body: `custom/upstream-pr-3.md`.

---

## Opening with `gh` (once authenticated)

```bash
gh pr create --repo dishwasher-detergent/mault \
  --head 4holdingdirectlimited:pr/fw-robustness --base master \
  --title "Harden firmware: id-correlated replies, fixed serial buffer, all-module jam watch, boot recovery" \
  --body-file custom/upstream-pr-1.md

gh pr create --repo dishwasher-detergent/mault \
  --head 4holdingdirectlimited:pr/fw-config --base master \
  --title "Persist servo calibration to EEPROM and add a scan light (LED 1)" \
  --body-file custom/upstream-pr-2.md

gh pr create --repo dishwasher-detergent/mault \
  --head 4holdingdirectlimited:pr/fw-state-machine --base master \
  --title "Rebuild firmware as a non-blocking state machine with interrupt-driven feeding" \
  --body-file custom/upstream-pr-3.md
```

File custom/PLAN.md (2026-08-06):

# Plan — faster + more robust card sorter (Arduino Uno R4 Minima)

> **Status: historical roadmap.** Everything under "Where the current firmware
> falls short" is shipped — the firmware is now a non-blocking state machine
> with EEPROM calibration, interrupt-driven IR and Wi-Fi/WebSocket/OTA (see
> `custom/CHANGES.md` items 49–59). Kept as the record of the v1 plan and the
> still-open physical commissioning checklist below.

Goal: keep the existing Arduino hardware and make the machine **faster** (higher
throughput, less dead time between cards) and **more robust** (no silent hangs,
no lost calibration, recovers from jams/timeouts cleanly).

All line references are to `arduino/main/main.ino` as of upstream `a1dfa44`
(unchanged in our copy). This is a draft roadmap — pick items per priority; each
is independently implementable.

## Where the current firmware falls short

### 1. Blocking, delay-heavy sequence — ~~the #1 bottleneck and robustness issue~~ ✅ rebuilt

`routeCard()` and `runFeeder()` used to block `loop()` for the entire feed +
routing sequence. They're now a **non-blocking state machine** (`runMachine()` in
`main.ino`): every mechanical phase advances on a timestamp or a sensor edge,
so serial stays responsive mid-operation. `{"cancel": true}` aborts any phase
back to neutral, jam alerts abort immediately, and commands arriving mid-run
get a clean `{"error":"busy"}` instead of being silently delayed.

### 2. Polled IR instead of edge detection — ~~leaves speed on the table~~ ✅ rebuilt

Module 1's IR sensor is now **interrupt-driven** (`attachInterrupt` on
`IR_PIN_MODULE1`): the feeder stops the instant the beam is crossed, and the
motor runs **continuously** (no pulse/pause cycling — the old
`pulseDuration`/`pauseDuration` feed cycling is gone). Module 2/3 sensors stay
polled, which is fine for routing waits.

### 3. Calibration is RAM-only — lost on every reboot ✅ built

`{"setConfig": ...}` and `{"setFeederConfig": ...}` write only to RAM
(`moduleConfig` L64–68, `feederConfig` L80). Re-powering the unit reverts to
stock pulses, so a tuned machine must be re-calibrated after every power cycle.

**Plan:** persist `moduleConfig` + `feederConfig` to EEPROM (Uno R4 Minima has
8 KB). Load on boot in `setup()` (L580–595), add `{"saveConfig": true}` /
`{"resetConfig": true}` commands.

### 4. `String` + line buffer — slow drift toward heap fragmentation

`String inputBuffer` (L87) plus `String` use in `handleCommand` fragment the
heap over long sessions. On an always-on sorter this eventually causes weird
crashes.

**Plan:** replace with a fixed `char` buffer + index, and avoid `String`
construction in the parser. (`ArduinoJson`'s `JsonDocument` is fine.)

### 5. Serial framing is fragile

Commands are newline-delimited with a 256-char cap that **silently discards**
the whole line on overflow (L597–611), and a truncated line is just ignored.
No CRC, no ACK contract, so a dropped byte = silently lost command mid-run.

**Plan:** keep newline framing but respond to every command (already done for
known commands — add explicit ACK for every path), and drop oversized lines
with an `{"error":"line too long"}` instead of silence. Optionally add a
start-of-command marker (e.g. `>` prefix) so partial garbage can be flushed.

### 6. Jam/error coverage is module-1-only, idle-only

The jam watch covers only module 1 and only between commands.

**Plan:** generalize `checkModule1Jam()` to all modules and the hopper, and run
the watch from the state machine even mid-sequence. Report `{"error":"jam","module":N}`
per module with per-module timeout config.

### 7. No per-phase watchdog

`waitForCard()` (L49–56) and the feeder have timeouts, but a stalled servo or a
stuck paddle during a *motion* phase blocks forever (e.g. the 600 ms `DELAY_PUSH`
is fixed, but a physically jammed pusher isn't detected).

**Plan:** every state in the machine gets a budget; exceeding it returns to
neutral and reports an error. Consider an MCU-level watchdog reset as a last
resort (R4 Minima: software watchdog via the Renesas core is limited — a
loop-level supervisor is the practical option).

## Speed items (independent of robustness)

- **Concurrent motions** — start opening the next module's bottom while the
  current pusher retracts (currently strictly sequential).
- **Re-tune timing with real measurements** — `DELAY_CARD_ENTER` 300 /
  `DELAY_PADDLE` 300 / `DELAY_PUSH` 600 ms and feeder pulse 80 / pause 50 /
  settle 150 ms are starting points, not optimized. Measure actual fall/push
  times and shrink safely.
- **Pipeline feed** — with the state machine, the feeder can start pulling the
  next card while the previous card is still being pushed, bounded by sensor
  state rather than fixed delays.
- *(Optional)* raise serial to 115200 baud — commands are small so 9600 is not
  the bottleneck, but telemetry/status streaming would benefit. **Note:** the
  web app hardcodes 9600 in `packages/web/src/features/scanner/api/use-serial.tsx`,
  so baud changes must be coordinated there.

## Power / electrical robustness (hardware side)

- Bulk capacitance on the servo rail (e.g. 1000–2200 µF) to absorb SG90/MG90S
  inrush — cheap insurance against brownouts that corrupt an in-flight sequence.
- Verify common ground between PSU, PCA9685 and Arduino (already called out in
  `arduino/main/BUILD.md`).
- Consider a soft-start for the feeder (ramp pulse instead of slam to full speed).

## Revised Bambu Lab print kit (planned)

DeckSift's own contribution to the *printable* side of the v1 machine: a
Bambu Lab quantity kit that reorganizes the original parts (same geometry,
from `3d model/`) into faster, more efficient print batches — fewer
color/material changes and better bed utilization. Not yet in the repo; the
original `Card Sorter.f3d` / `card_sorter.3mf` files remain the canonical
parts, with full credit to the original designer (see `README.md` Credits).

- [ ] Produce the quantity sheet + reorganized plate layout for Bambu Studio
- [ ] Add the kit files under `3d model/` alongside the originals
- [ ] Wire the kit into the `/build` guide and `arduino/main/BUILD.md`

## Suggested order of work

1. ~~Fixed serial buffer + oversized-line error (5)~~ ✅
2. ~~EEPROM persistence for calibration (3)~~ ✅
3. ~~Non-blocking state machine (1)~~ ✅
4. ~~Interrupt-driven IR feeding (2)~~ ✅ — the throughput win
5. Watchdog budgets per phase (7), full jam coverage (6) — partially done (whole-op watchdog + jam abort exist; per-phase budgets are implicit in each phase's timeout)
6. Concurrent/pipelined motions — last, once the machine is deterministic

## Machine build commissioning checklist

For when the physical sorter is assembled. Verify each link independently before
end-to-end tuning so a timing problem isn't mistaken for a vision or routing
problem. Software pre-reqs are noted inline.

1. **Camera / vision** (EMEET C60E 4K replacing the Logitech):
   - 4K stream at the capture crop; contour/perspective warp clean on a real
     card in the rig; no glare zone.
   - Time one full scan in the browser (capture → embed → match → UI). Compare
     with `pnpm bench:vectorize` (~380 ms DML on this machine).
   - RTX 3080 later: `VECTORIZE_DEVICE=dml` already works on NVIDIA; optional
     fp16 dtype; re-run the bench to confirm.
2. **Firmware timing** (measure, don't guess):
   - Actual feed time (hopper → module 1 IR) at the configured feeder speed.
   - Stopwatch each bin's sort path, then shrink `DELAY_*` constants safely.
   - Tune feeder speed/settle; verify no double-feed (two cards tripping IR).
3. **Pipeline** (the 2 s/card target):
   - Confirm the current serial flow is feed → scan → sort with NO overlap
     (verified in code, ~2.9–3.5 s/card) and time it on hardware.
   - Then implement the non-blocking state machine + pipeline feed (next card
     fed + scanned while the previous is being sorted). Target per-card
     ≈ scan + sort ≈ 1.7–2.2 s on shallow bins.
4. **Bundle workflow** (software now built — `custom/SETUP.md`):
   - 4-rarity bundle on bins 1–4 (or any rarity/bin mapping you set in the
     Bundle Mode panel); counts reach targets; duplicates → reject bin;
     bundle-complete pause; resume after restart. Remaining work is purely
     physical: verify the reject bin (catch-all bin 7) is where you expect and
     that bin routing lines up with the machine.
5. **Holo detection** (classifier thresholds need calibration):
   - The two-frame scan light is built (firmware LED 1 / PCA9685 ch0,
     smart skip if clearly matte). Wire the LED (see BUILD.md) and calibrate
     `FOIL_SECOND_FRAME_THRESHOLD` / `FOIL_DIFF_THRESHOLD` on real captures.
   - Collect labeled scans (manual foil toggle) during early runs; train the
     embedding classifier; verify on DBZ/One Piece foils — foil is a different
     product ID there, so detection feeds card identity, not just a badge.

## Related docs

- `custom/TCGS.md` — top-20 TCG plan, data-source status, adding games.
- `arduino/main/SERIAL_PROTOCOL.md` — current JSON contract (will grow: cancel, save/reset config, per-module jam timeouts).
- `arduino/main/BUILD.md` — wiring/BOM notes (PSU, capacitance, scan light).

## v2 machine — faster & more accurate sorting

> Full production review (materials, mass/stability, mechanism hardening,
> multi-machine architecture): **`HARDWARE_V2.md`**. The section below is the
> machine-level summary.

Ideas for a second build (or a major refit of this one). Goals: shorter
per-card time, fewer stripped parts, and sensor-confirmed motion instead of
blind timing.

### Servo upgrade: SG90 → MG90S

- **Why** — SG90 plastic gears strip under sustained pushing (the #1 field
  failure). MG90S has **metal gears + ~2.2 kg·cm torque** (vs ~1.8) at similar
  speed (~0.1 s/60°), so routes stay fast and repeatable for much longer.
- **Wiring** — pin-compatible drop-in (same PWM, 4.8–6 V). The higher stall
  current (~700 mA vs ~250 mA each) needs the servo rail's bulk capacitance
  bumped (2200 µF, see Power notes above) and the 5 V PSU sized for peak
  current, not steady state.
- **Consider also** — the R4 Minima's timers can drive up to ~12 servos
  natively; dropping the PCA9685 for direct timer PWM removes a driver stage
  and lets each servo run at its own calibration. (Keep PCA9685 for the LEDs
  + scan light.) Only worth it if the state-machine timing demands tighter
  control than the PCA9685's 1.6 kHz update gives.

### Card detection: faster, more reliable

Current: IR through-beam sensors polled every ~5 ms inside `interruptibleDelay`
while the feeder pulses — the card is only caught when a poll happens to see it,
and a full `delay()` cycle can be missed. Options for v2, best-first:

1. **Interrupt-driven edges** — `attachInterrupt` on the module-1 + hopper
   sensors (both already on interrupt-capable pins D2–D5). Stop the feeder the
   instant the beam is crossed; no polling, no missed edges. This is the
   single biggest speed win (feeder can run continuously instead of pulsed).
2. **Comparator front-end** — a Schmitt-trigger/op-amp stage (e.g. LM393)
   turns the analog sensor into a clean digital edge, eliminating the slow
   analog-transition zone where a card can sit half-detected. Cheap, bulletproof.
3. **Optical encoder on the feeder roller** — a slotted wheel + IR pair
   measures actual feed distance, so “card at module 1” is confirmed by
   distance *and* beam, not a fixed pulse time. Enables precise stop position
   and double-feed detection (encoder continues moving while the beam is
   already broken).
4. **Camera as feedback** — the scan camera already sees the card; a motion
   check in the capture region can confirm “arrived + settled” without extra
   hardware. Useful as a cross-check, not a primary sensor (slower loop).

### What stays (already in the roadmap above)

- Non-blocking state machine (section 1) — prerequisite for interrupt feeding.
- Per-phase watchdog budgets (section 7) — with faster motion, a missed edge
  must still abort safely.
- Pipelined feed (Speed items) — next card feeds while the previous routes.

### Target

With interrupt feeding + MG90S + pipelining: **~1.5–2 s/card** on shallow
bins (vs the current ~3 s baseline) with sensor-confirmed, jam-safe motion.

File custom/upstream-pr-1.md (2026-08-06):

## Why
The machine can lose a card to a silent failure: a dropped serial byte
mid-route, a jam nobody notices, or a power blip that leaves a card sitting
in the mechanism. Each of these previously just hung or dropped the command.

## What changed
- **Id-correlated replies** — every command may carry an optional `id`; all
  replies echo it, so the host can match responses even while asynchronous
  messages (jam alerts) arrive in between. No more mistaking one reply for
  another.
- **Fixed-size serial buffer** — the `String` accumulator is replaced by a
  fixed `char` buffer; oversized lines are discarded with a clean
  `{"error":"line too long"}` instead of silently truncating.
- **Jam watch on all modules** — a card sitting at any module gate for longer
  than the timeout (no routing command in flight) reports `{"error":"jam"}`,
  not just module 1.
- **Boot recovery report** — if the board boots with a card already at a
  gate (power loss mid-run), it reports `{"error":"recovered","module":N}` so
  the operator flushes the device before feeding.

## Testing
1. Flash to an Uno R4 Minima (libraries: ArduinoJson, Adafruit PWM Servo Driver).
2. Send `{"test":true,"id":1}` — the reply echoes `"id":1`.
3. Hold a card at a module gate for the jam timeout — expect `{"error":"jam","module":N}`.
4. Send an oversized line — expect `{"error":"line too long"}`.

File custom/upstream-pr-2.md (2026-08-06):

## Why
Calibration was RAM-only: every reboot reverted a tuned machine to stock
pulses. Also, holo/foil detection needs a second, differently-lit capture —
the build guide's "spare" channel 14 LED was never wired by anyone.

## What changed
- **EEPROM calibration persistence** — `{"setConfig":...}` and
  `{"setFeederConfig":...}` save to EEPROM automatically; `{"saveConfig":true}`
  persists explicitly; `{"resetConfig":true}` restores factory defaults. A
  magic/version guard ignores stale data from older firmware.
- **Scan light on LED 1 (ch0)** — the holo-detection light now uses the
  on-board LED 1 channel instead of spare channel 14: `{"led":1,"on":true}`.
  Wiring stays on the existing PCB, no spare-channel cable. (LEDs 2-4 on
  ch1-3 remain free as indicator lamps.)
- Safe defaults while uncalibrated: module pulses are all within a few µs of
  each other so a freshly-flashed board cannot over-travel and strip a gear.

## Testing
1. Flash, then `{"setConfig":{"module":1,"bottomClosed":150,...}}`.
2. Reboot — the tuned values survive (`{"readConfig":true}` or observe motion).
3. `{"led":1,"on":true}` lights LED 1 on ch0.

> Note: this branch supersedes the earlier "scan light (LED 5)" version —
> the scan light moved to LED 1/ch0 to keep the wiring on existing hardware.

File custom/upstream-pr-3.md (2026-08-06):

## Why
Feed/route/test/clear were blocking `delay()` sequences: serial froze for
the whole operation, so a jam mid-route was invisible until it timed out,
and the feeder could only pulse (polling IR) instead of running continuously.

## What changed
This is the firmware rework the other two PRs build toward — it includes the
robustness fixes (id-correlated replies, fixed serial buffer, jam watch) and
the config persistence + scan light from the sibling PRs, so this branch is
the complete modern firmware.

- **Non-blocking state machine** — every operation is a phase machine driven
  from `loop()`: `{"cancel":true}` aborts any phase to neutral, jam alerts
  abort immediately, commands arriving mid-run get a clean `{"error":"busy"}`,
  and a whole-operation watchdog replaces per-command deadlines.
- **Interrupt-driven module-1 IR** — the feeder stops the instant the beam is
  crossed (`attachInterrupt`), so the motor runs continuously instead of
  pulse/pause cycling. This is the biggest single throughput win.
- **Scan light on LED 1 (ch0)** for two-frame holo detection.

## Testing
1. Flash; confirm `{"status":"ready"}`.
2. `{"bin":1}` — watch the route run while `{"ping":true}` still answers
   mid-route.
3. Send `{"cancel":true}` mid-route — returns to neutral cleanly.
4. Feed: the feeder runs continuously and stops the moment the card reaches
   module 1's sensor.
5. Hold a card at a gate — jam alert aborts any active operation.

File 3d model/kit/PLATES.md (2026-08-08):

# Print plates — `card_sorter_decksift.3mf` (16 plates)

The DeckSift print-optimized 3MF lays the machine's **30 parts** across **16
plates**. Each plate's preview is embedded in the file as
`Metadata/plate_N.png` (also `plate_N_small.png`); the per-plate contents
below are a guide, not a substitute for the preview — Bambu Studio shows the
exact arrangement.

| Plate | Likely contents (verify against preview) |
| --- | --- |
| 1 | Enclosure / base halves |
| 2 | Base + base panels |
| 3 | Module 1 housing parts |
| 4 | Module 1 flappers + pusher arm |
| 5 | Module 2 housing parts |
| 6 | Module 2 flappers + pusher arm |
| 7 | Module 3 housing parts |
| 8 | Module 3 flappers + pusher arm |
| 9 | Bin bases 1–4 |
| 10 | Bin bases 5–7 + bin catches |
| 11 | Hopper tube + wall |
| 12 | Feeder roller + mounts |
| 13 | IR sensor mounts + small brackets |
| 14 | Wire channels / zip-tie guides |
| 15 | Lid / top pieces |
| 16 | Remaining small parts / spares |

Print in plate order (structural first, per BUILD.md). If a plate looks
under-filled, group it with an adjacent plate manually — the kit favors
correct grouping over strict plate count.

Total check: **30 objects**, each on exactly one plate. If your Bambu Studio
version shows a different split, use the preview as the source of truth.

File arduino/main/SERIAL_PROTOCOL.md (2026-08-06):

# Serial protocol — `main.ino`

The firmware communicates over USB serial at **9600 baud**, one JSON object per line. The web app uses the Web Serial API; anything can talk to it (Serial Monitor, scripts, etc.).

On ESP32-S3 boards the same protocol is also served over a **WebSocket on port 81** when Wi-Fi is configured (see [Wi-Fi / WebSocket transport](#wi-fi--websocket-transport-esp32-s3-only) below) — both transports speak the same JSON, so the web app can drive the machine over USB or Wi-Fi interchangeably.

**Frame format:** newline- (`\n` or `\r`) terminated JSON. Lines longer than 256 characters are discarded.

## Wi-Fi / WebSocket transport (ESP32-S3 only)

The ESP32 firmware build can join your LAN and serve the identical JSON protocol over a WebSocket:

- **Configure once:** send `{"wifi":{"ssid":"…","password":"…"}}` (usually over USB on first setup). The credentials are stored in EEPROM and the board joins the network on every boot.
- **Address:** the board registers mDNS as `decksift-board.local` and listens for WebSockets on **port 81** — `ws://decksift-board.local:81` (use the IP if mDNS isn't available). Change `WIFI_HOSTNAME` in the sketch per machine for multi-rig setups.
- **Handshake:** when a WebSocket client connects, the firmware sends the same `{"status":"ready","proto":2}` boot line it sends on USB reset, so the web app's connect flow (ready → protocol check → mechanical test) is identical on both transports.
- **Replies:** every line the firmware emits (command replies, boot ready, async jam alerts) goes to USB serial **and** is broadcast to any connected WebSocket client. Id-correlated replies keep the two transports unambiguous.
- **OTA:** with Wi-Fi configured, the Arduino IDE can flash updates over the network (Sketch → Upload Using a Network Port). The orange comms LED is lit during an OTA update.
- **Not breaking USB:** boards without Wi-Fi (Uno R4, Pico, STM32) compile without this section; the USB flow is unchanged.

## Command ids (request/response correlation)

Every command may carry an optional numeric `"id"` field. When present, the firmware echoes it on **every reply to that command**:

```json
{"bin": 3, "id": 17}
{"status":"routed","bin":3,"id":17}
```

The web app uses this to correlate responses to requests instead of assuming "the next line is the answer". Messages that are **not** replies to a command — the boot `{"status":"ready"}` line and asynchronous `{"error":"jam",...}` alerts — never carry an id, so they can never be mistaken for a command's response.

Commands without an `id` are answered without one (backward compatible).

## Boot

On reset the board replies with its status and the protocol version (used by
the web app to detect app/firmware mismatches):

```json
{"status":"ready","proto":2}
```

## Commands

### Route a card

```json
{"bin": 1}
```

Runs the full feed + routing sequence. `bin` must be 1–7:

| Bin | Route |
| --- | --- |
| 1 | Module 1: open paddle, push **left** |
| 2 | Module 1: open paddle, push **right** |
| 3 | Module 1 bottom open → Module 2, push **left** |
| 4 | Module 1 bottom open → Module 2, push **right** |
| 5 | M1 → M2 → Module 3, push **left** |
| 6 | M1 → M2 → Module 3, push **right** |
| 7 | All bottoms open (catch-all) |

On success:

```json
{"status":"routed","bin":1}
```

On failure (hopper empty / timeout), an error is emitted and all servos return to neutral:

```json
{"error":"empty: feeder hopper is out of cards","empty":true}
{"error":"timeout: feeder did not deliver card to module 1","empty":false}
{"error":"timeout: no card detected at module 2"}
{"error":"timeout: no card detected at module 3"}
```

### Mechanical test

```json
{"test": true}
```

Opens every bottom and paddle, sweeps all pushers left then right, resets to neutral, spins the feeder ~500 ms, cycles the 4 LED channels. Replies:

```json
{"status":"test_complete"}
```

### Liveness check

```json
{"ping": true}
```

Replies immediately — the web app uses this as a heartbeat to detect a hung
or unresponsive board within seconds:

```json
{"status":"pong"}
```

### Reset to neutral

```json
{"neutral": true}
```

```json
{"status":"ok"}
```

### Flush the device

```json
{"clearDevice": true}
```

Opens every module's bottom trapdoor at once so any card resting in the mechanism drops through to the catch-all, then returns to neutral. Does **not** run the feeder (unlike `{"bin": 7}`). Replies:

```json
{"status":"cleared"}
```

### LEDs (channels 0–3)

```json
{"led": 1, "on": true}   // LED 1 = scan light (ch0)
{"led": 2, "on": true}   // LED 2 = green “operating” (ch1)
{"led": 3, "on": true}   // LED 3 = red “machine fault” (ch2)
{"led": 4, "on": true}   // LED 4 = orange “software/comms fault” (ch3)
```

`led` is 1–4, mapped to channels 0–3.

- **LED 1 (ch0) — scan light** — the angled holo-detection light, driven by
  the web app for two-frame foil scans (frame with light off → toggle → frame
  with light on).
- **LEDs 2–4 (ch1–3) — status lamps** — the firmware drives these itself
  (green while an operation runs, red on jam/timeout/fault, orange on bad
  JSON or an oversized line). The web app mirrors the same state in the UI
  and re-asserts it over serial.

Replies:

```json
{"status":"ok","led":1,"on":true}
```

### Move a single servo — named position

```json
{"servo":"paddle","module":1,"position":"open"}
```

`servo`: `bottom`, `paddle`, or `pusher`. `module`: 1–3. `position`:
- bottom/paddle: `open` or `closed`
- pusher: `left`, `neutral`, or `right`

Replies after a 200 ms settle:

```json
{"status":"ok","servo":"paddle","module":1}
```

### Move a single servo — raw PWM (calibration preview)

```json
{"servo":"bottom","module":1,"value":220}
```

Writes the raw PWM pulse (clamped to 120–490) directly. Replies:

```json
{"status":"ok","servo":"bottom","module":1}
```

### Set module config (RAM only)

```json
{"setConfig":{
  "module":1,
  "bottomClosed":150,"bottomOpen":307,
  "paddleClosed":150,"paddleOpen":307,
  "pusherLeft":150,"pusherNeutral":307,"pusherRight":460
}}
```

All fields optional — omitted ones keep their current value. Replies:

```json
{"status":"ok","module":1}
```

### Run the feeder

```json
{"feeder": true}
```

Feeds until the module 1 IR detects a card, the hopper reads empty, or the feed duration elapses. Replies:

```json
{"status":"ok","detected":true,"empty":false}
```

**Queued feed (pipelining):** if a feed arrives while another operation is
running, the firmware queues it and replies **only when the queued feed
completes** (with the original command id) — so the caller sees the card
arrive rather than a "busy" error. This is what lets the web app request the
next card while the current one is still being routed.

```json
{"cancelFeed": true}
```

Drops a still-pending queued feed (used when routing fails so the next card
must not be pulled). Does not stop a feed already in flight. Replies
`{"status":"ok"}`.

### Feeder raw PWM (calibration preview, no auto-stop)

```json
{"feederValue": 400}
```

```json
{"status":"ok"}
```

### Stop the feeder

```json
{"feederStop": true}
```

Cuts the PWM signal entirely (the only reliable way to stop a 360° servo). Replies:

```json
{"status":"ok"}
```

### Set feeder config

```json
{"setFeederConfig":{
  "speed":400,
  "duration":3000,
  "pulseDuration":80,
  "pauseDuration":50,
  "settleDuration":150
}}
```

- `speed` — PWM pulse for forward motion
- `duration` — overall timeout (ms) before giving up
- `pulseDuration` — ms to run the motor per pulse (0 = continuous feed, no pulsing)
- `pauseDuration` — ms to pause between pulses (IR checked after each stop)
- `settleDuration` — ms to keep feeding after the IR first sees the card so it fully enters the module 1 mechanism

Replies:

```json
{"status":"ok"}
```

### Set routing timing (delays, persisted with saveConfig)

```json
{"setTimingConfig":{
  "cardEnterMs":300,
  "paddleMs":300,
  "pushMs":600
}}
```

Runtime-tunable replacements for the old compile-time `DELAY_*` constants:
- `cardEnterMs` — time for the card to settle after the target bottom opens (50–2000)
- `paddleMs` — time for the paddle to engage (50–2000)
- `pushMs` — time for the pusher to complete its stroke (100–3000)

Values are clamped to the bounds above and echoed back in the reply:

```json
{"status":"ok","timing":{"cardEnterMs":300,"paddleMs":300,"pushMs":600}}
```

Send `{"saveConfig": true}` afterwards to persist across reboots.

### Save config to EEPROM

```json
{"saveConfig": true}
```

Persists the current module + feeder config to EEPROM so a reboot (e.g. a
power blip mid-run) restores the tuned values. Note that `setConfig` and
`setFeederConfig` already save automatically. Replies:

```json
{"status":"saved"}
```

### Reset config

```json
{"resetConfig": true}
```

Restores factory defaults in RAM and EEPROM and returns all servos to
neutral. Replies:

```json
{"status":"reset"}
```

### Read IR sensors

```json
{"readIR": true}
```

Replies (booleans are `true` = card present):

```json
{"status":"ok","ir":[false,false,false],"hopper":true}
```

`ir[0..2]` = modules 1–3, `hopper` = cards remain in the feeder stack.

### Configure Wi-Fi (ESP32-S3 only)

```json
{"wifi":{"ssid":"MyWiFi","password":"secret"}}
```

Stores the credentials in EEPROM and joins the network in the background
(safe while the machine is running). `ssid` must be 1–32 chars, `password`
≤ 63 chars. Replies:

```json
{"status":"ok","wifi":{"saved":true,"ssid":"MyWiFi"}}
```

Once connected the firmware announces its address over both transports:

```json
{"status":"wifi","ip":"192.168.1.50"}
```

### Read Wi-Fi status (ESP32-S3 only)

```json
{"getWifi": true}
```

Replies with the saved network and current connection state:

```json
{"status":"ok","wifi":{"ssid":"MyWiFi","connected":true,"ip":"192.168.1.50","hostname":"decksift-board","wsPort":81}}
```

### Forget Wi-Fi (ESP32-S3 only)

```json
{"wifiForget": true}
```

Erases the credentials from EEPROM and disconnects from the network. Replies `{"status":"ok"}`.

## Events & errors

The firmware can emit these without a request:

| Message | Meaning |
| --- | --- |
| `{"status":"ready","proto":2}` | Boot complete — `proto` is the protocol version the app uses to detect mismatches |
| `{"error":"jam","module":N}` | A card has sat at module N's (1–3) sensor for > 20 s with no routing command in progress (idle-time jam watch) |
| `{"error":"recovered","module":N}` | Emitted once on boot if a card was already resting at module N's sensor (e.g. power loss mid-run) |
| `{"error":"aborted: jam detected","aborted":true}` | An operation was aborted mid-way (jam reported or watchdog deadline) and all servos returned to neutral |
| `{"error":"invalid JSON"}` | Line failed to parse |
| `{"error":"unknown command"}` | Valid JSON but no recognized field |
| `{"error":"bin must be 1-7"}` / `{"error":"module must be 1-3"}` / `{"error":"servo must be bottom, paddle, or pusher"}` / `{"error":"invalid position"}` / `{"error":"led must be 1 to 4"}` / `{"error":"ssid must be 1-32 characters"}` / `{"error":"password must be at most 63 characters"}` | Bad arguments |

## Notes

- **Transports:** every line goes to USB serial; on ESP32 with Wi-Fi it is also
  broadcast to WebSocket clients (port 81, mDNS `decksift-board.local`). See
  the [Wi-Fi section](#wi-fi--websocket-transport-esp32-s3-only) at the top.
- Motion waits are **interruptible** — the jam watch runs *during* operations
  (not just between them), and each command has a watchdog budget
  (`commandGuardStart`). On a jam or deadline the operation aborts to neutral
  with `{"error":"aborted: jam detected","aborted":true}`.
- Configuration (`setConfig`, `setFeederConfig`) is persisted to **EEPROM** —
  both apply to RAM *and* save, so a reboot restores the tuned values.
  `{"saveConfig": true}` and `{"resetConfig": true}` manage persistence
  explicitly. Stored data is version-guarded: if the firmware's config layout
  changes (or a servo swap invalidates old values), stale data is ignored and
  factory defaults are used.
- `runFeeder()` checks the module 1 sensor **before** the hopper sensor, so the last card in an empty hopper still routes correctly.
- The jam watch only runs between commands — routing/feeding blocks `loop()` for their duration.

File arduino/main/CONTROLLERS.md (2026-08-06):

# Controllers — wiring, power, and support status

One firmware sketch (`main.ino` + `board-config.h`) runs on several
controllers. This page is the honest wiring guide per board: **compiling is
not the same as being wired right**, and the 3.3 V boards need different
connections than the 5 V Arduino.

> **ESP32-S3 DevKitC-1 owners:** a complete pin-by-pin wiring guide for the
> common CH343-bridged dev board is in [`WIRING_S3.md`](WIRING_S3.md) — header
> layout, PCA9685, IR sensors, LEDs, power, and flashing.

## Support status (be honest about what's verified)

| Board | Compiles | Flashing docs | Wiring verified on hardware |
| --- | --- | --- | --- |
| **ESP32-S3** | ✅ (CI + local) | ✅ (`README.md` → ESP32-S3 settings) | ⚠️ Partially — flashed + protocol + EEPROM persistence verified on a CH343 dev board; full machine wiring not commissioned |
| **Arduino Uno R4 Minima** | ✅ (CI + local) | ✅ | ✅ — the original reference build |
| **RP2040 / Pico** | ✅ (local) | — | ❌ not wired/commissioned |
| **STM32 (GenF4)** | ✅ (local) | — | ❌ not wired/commissioned |

Until a board has been wired and a full calibration run completed, treat
machines on it as **experimental** — the sketch is portable, but the machine
wiring has only been proven on the Uno R4. The ESP32-S3 has been verified
flashing + speaking the protocol + persisting calibration on a real dev
board (see below).

## The one thing that matters most: logic levels

| Board | I/O voltage | 5 V tolerant inputs? |
| --- | --- | --- |
| Arduino Uno R4 Minima | 5 V | Yes (it *is* 5 V) |
| **ESP32-S3** | **3.3 V** | **NO — feeding 5 V into a GPIO can damage the chip** |
| RP2040 / Pico | 3.3 V | NO |
| STM32 (GenF4) | 3.3 V | NO (check the specific part; many are not) |

Consequences for the machine wiring:

1. **IR sensors** — use 3.3 V-compatible IR sensor modules (most modern
   modules accept 3.3–5 V). If yours is powered at 5 V, its *output* is also
   5 V → add a voltage divider (two resistors, e.g. 1 kΩ / 2 kΩ) or a level
   shifter between the sensor OUT and the board's GPIO. The firmware reads
   them with internal pull-ups at the board's I/O voltage, so a 3.3 V module
   works unchanged.
2. **Servo signals stay 5 V (correct)** — the PCA9685's PWM outputs are
   driven at its `V+` supply (the external 5 V PSU), not at logic VCC. So the
   SG90s get proper 5 V signals regardless of the controller. **Do not** feed
   the PCA9685's outputs back into the controller.
3. **PCA9685 logic** — power `VCC` from the board's 3.3 V on a 3.3 V
   controller (the PCA9685 logic is 3.3–5 V), keep `V+` on the external 5 V
   PSU for the servos, and tie the PSU ground to the board ground AND the
   PCA9685 ground (common ground is mandatory — the #1 cause of twitchy
   servos).

## Pin map differences

`board-config.h` defaults the IR pins to GPIO 2–5 (valid on every board) and
the PCA9685 I2C to the board's default `Wire` pins — except ESP32-S3, where
I2C is explicitly GPIO 8 (SDA) / 9 (SCL). Every pin is overridable at build
time with `-D<NAME>=n`:

| Macro | Uno R4 | ESP32-S3 (default) | ESP32-S3 (recommended build) | Pico | STM32 |
| --- | --- | --- | --- | --- | --- |
| `IR_PIN_MODULE1` | D2 | 2 | **6** | 2 | your pins |
| `IR_PIN_MODULE2` | D3 | 3 | **7** | 3 | ↑ |
| `IR_PIN_MODULE3` | D4 | 4 | **10** | 4 | ↑ |
| `IR_PIN_HOPPER` | D5 | 5 | **11** | 5 | ↑ |
| `I2C_SDA` | A4 (default) | 8 | 8 | default | your pins |
| `I2C_SCL` | A5 (default) | 9 | 9 | default | ↑ |

Why the recommended ESP32-S3 pins: GPIO 3 is the JTAG pin and GPIO 0/3/45/46
are strapping pins on the S3 — the defaults work as inputs, but the
recommended set (6/7/10/11) avoids every special-function pin and is fully
interrupt-capable.

Example override (PlatformIO):

```ini
build_flags =
  -DIR_PIN_MODULE1=6 -DIR_PIN_MODULE2=7 -DIR_PIN_MODULE3=10 -DIR_PIN_HOPPER=11
```

(Arduino IDE: Tools → "Extra flags for build" / `-D` entries, or edit the
`#ifndef` defaults in `board-config.h`.)

## Power

- **External 5 V PSU (4–10 A)** into PCA9685 `V+` — the servo rail. The
  SG90s can pull 250 mA each and the feeder more; the USB 5 V on a dev board
  is not enough for 10 servos.
- ESP32-S3 dev boards: power the logic from USB (5 V) — the on-board LDO
  makes 3.3 V for the chip and the PCA9685 VCC.
- Common ground: PSU GND → PCA9685 GND → board GND. Always.
- Bulk capacitance (1000–2200 µF) on the servo rail is cheap insurance
  against brownouts that corrupt an in-flight sequence.

## Boot / serial notes

- **ESP32-S3 — two serial paths**, pick the one your board actually exposes:
  - **USB-serial bridge (CH340/CH343/CP2102) — the common dev board**: keep
    the Arduino IDE defaults (**USB CDC On Boot: Disabled**) so `Serial` maps
    to UART0 through the bridge. Flash + Web Serial both use that port.
    Verified on a CH343 dev board.
  - **Native USB only** (no bridge chip): enable **USB CDC On Boot** so
    `Serial` maps to the native USB port.
- **ESP32-S3 — Wi-Fi / WebSocket / OTA (optional, additive):** with saved
  credentials the firmware joins your LAN (mDNS `decksift-board.local`,
  WebSocket port 81) and accepts Arduino IDE network updates. The browser can
  then drive the machine over Wi-Fi instead of USB. Configure from the app at
  Calibrate → **Wi-Fi & OTA**; protocol details in `SERIAL_PROTOCOL.md`.
  Boards without Wi-Fi (Uno R4, Pico, STM32) are unaffected.
- **RP2040 / STM32**: native USB CDC enumerates as a serial port — no extra
  settings. STM32 "USB on Boot" is enabled by default on most generic boards.
- Uno R4: real EEPROM, no special settings.
- The firmware waits up to 5 s for the USB serial to enumerate, then proceeds
  — a headless power-on won't hang.

## Adding a new board

1. Add its `ARDUINO_ARCH_*` branch to `board-config.h` (EEPROM init, I2C
   pins, interrupt attach).
2. Compile it locally (`arduino-cli compile --fqbn <core>:<board>`).
3. Add a row to the support table above — and only mark wiring "verified"
   after a real machine has been calibrated on it.

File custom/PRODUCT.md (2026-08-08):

# Product strategy — v1 (home) → v2 (commercial)

Two product tiers, one codebase. **v1 is the adoption vehicle; v2 is the
hardened commercial build.** Everything in v2 is measured/justified by v1
usage first (see `HARDWARE_V2.md` for the measurement gate).

## Positioning

| | v1 — “Home Sorter” | v2 — “Pro / Commercial” |
| --- | --- | --- |
| Who | Home collectors/sellers, hobbyists | Card shops, bulk buyers, small production |
| Hardware | Current machine: PLA/PETG, SG90, ~$250 parts | Hardened: ASA/steel base, MG90S + bearings, sleeve-tolerant, ~$1k+ parts |
| Software | Same app, local, free for personal use | Same app + multi-machine, digitize/listing workflows, support |
| Adoption goal | **Get it into homes first** — trust, fun, correct | Sell units + service, justify the $ premium |
| Price | Free for personal use (source available, license in `LICENSE`) | Sold by license from 4holdingdirectlimited — others may not sell DeckSift commercially |

**Licensing (2026):** DeckSift is source-available and free for personal,
non-commercial use. Commercial use — selling DeckSift or building it into a
product — requires a license from 4holdingdirectlimited, who sell the upgraded
v2 product. The MAULT-derived portions (original Fusion design, build photos,
firmware base) remain MIT (see `LICENSE`).

**Why v1 first:** v1 adoption is what funds v2 — community calibration data
(foil labels), real-world feedback, a proven throughput baseline, and word of
mouth. v2's premium is only believable once v1 works flawlessly at home.

## What v1 needs to be (adoption drivers)

1. **Correctness > speed** — a home user forgives slowness, not misroutes.
2. **Trust/visibility** — they can see what the machine did and undo it.
3. **Easy setup** — from box to first successful sort in an afternoon.
4. **Fun feedback** — sounds, stats, progress.
5. **No surprises** — clear errors, safe pauses, obvious bin status.

## Feature backlog (value vs effort)

Legend: effort ●○○ = tiny (hours) · ●●○ = a session · ●●● = a project.
✅ = built · 🔜 = next · 🧰 = v2/optional

### Setup & trust (highest value for adoption)

| Feature | What | Effort | Status |
| --- | --- | --- | --- |
| First-run checklist | Guided: connect camera → Arduino → calibrate → sync → first scan | ●●○ | ✅ built |
| Undo last scan | Remove the most recent record (fix by hand if misrouted) | ●○○ | ✅ built |
| Match/no-match sounds | Distinct chime vs low tone so you know without looking | ●○○ | ✅ built |
| Match confidence badge | Show distance/quality on each scanned card | ●○○ | ✅ built |
| Scan stats (value, sets, rares) | Already computed — surface it better (sidebar) | ●○○ | ✅ part |
| Backup/restore | `pg_dump` script wrapper — one command, full safety net | ●○○ | ✅ built (`scripts/backup-db.mjs`) |
| Collection CSV import | Import ManaBox/TCGplayer list → “owned” data feeds chase/set-completeness instantly | ●●○ | ✅ built |
| Review queue | Low-confidence matches pause for a yes/no instead of auto-routing | ●●○ | ✅ built |

### Value & commerce (bridge to v2)

| Feature | What | Effort | Status |
| --- | --- | --- | --- |
| TCGplayer CSV export | Inventory CSV for the seller portal | ●○○ | ✅ built |
| Bundle SKU + inventory + CSV | Traceable bundle records | ●●○ | ✅ built |
| Total collection value | Per-session + per-collection totals | ●○○ | ✅ part |
| Condition field | Per-scan condition for TCG export (defaults NM) | ●●○ | ✅ built |
| TCGplayer price source | Needs API keys — TCGplayer froze new grants (verified 2026-08); parked until keys exist (TCGS.md roadmap) | ●●● | 🧰 |

### Everyday QoL

| Feature | What | Effort | Status |
| --- | --- | --- | --- |
| Keyboard shortcuts | Space = pause/resume, S = scan, Z = undo | ●○○ | ✅ built |
| Digitize mode | Record without sorting | ●○○ | ✅ built |
| Orientation tolerance | Auto-upright flipped cards | ●○○ | ✅ built |
| Feeder “clear” button | Quick jam-recovery without full recalibration | ●○○ | 🔜 |
| Session timer pause on bin-full | Already pauses — make the reason obvious in the overlay | ●○○ | ✅ part |
| Per-set completeness % on scan | “7/40 of this set” toast when set is detected | ●○○ | ✅ built |

## Quick wins I can build next (your pick)

1. **Match confidence badge** on scanned cards (distance → colored dot) — tiny,
   huge trust boost. — ✅ built (Item 47)
2. **Keyboard shortcuts** (pause/scan/undo) — tiny. — ✅ built (Item 47)
3. **Backup/restore script** — one-command `pg_dump`/`pg_restore` wrapper,
   tiny, big peace of mind. — ✅ built (Item 47)
4. **Collection CSV import** — medium, but it unlocks chase mode + set
   completeness for people with existing collections (strong adoption hook).
   — ✅ built (Item 47)

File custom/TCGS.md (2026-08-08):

# Multi-TCG support plan

Goal: the sorter handles any trading card game through the same scan → match →
bin → bundle pipeline. The vision model (SigLIP) is game-agnostic; the game
differences live entirely in the **card data adapters**.

## The architecture (built, `packages/server/src/lib/card-search/`)

- **`generic.ts`** — config-driven adapter factory. One code path implements
  search, by-id lookup, and bulk sync; a game contributes only a **config**
  (URLs + field mapping). No per-game adapter files.
- **`generic-configs.ts`** — the configs. Each is ~40 lines of data.
- Per-game pieces that remain: registering the config in
  `resolve.ts` (search) + `sync-job.ts` (sync), adding image hosts to the
  proxy allowlist in `routes/card.ts`, and creating the game row in the web
  admin UI (Settings → Games) with its rarity field definitions.

## Games wired and verified (2026-08)

| Game | Source | Status |
| --- | --- | --- |
| MTG | Scryfall | ✅ built-in adapter, synced (54,009 rows, full card data) |
| Gundam | gundam-gcg.com | ✅ built-in adapter, synced (1,816 rows — card data backfilled 2026-08) |
| Pokémon | TCGdex | ✅ built-in adapter, synced (21,756 rows, full card data) |
| **Yu-Gi-Oh!** | YGOPRODeck (`db.ygoprodeck.com/api/v7`) | ✅ generic config, endpoints verified (search + byId + images) — synced (14,477 rows) |
| **Digimon** | digimoncard.io (`search.php`) | ✅ generic config, endpoints verified (search + bulk + images) — synced (4,373 rows with images; the rest of the ~9k catalog lacks usable artwork) |
| **Lorcana** | lorcana-api.com (`api.lorcana-api.com/cards/all`) | ✅ generic config, added 2026-08 (2,694 cards, 13 sets, official Ravensburger art, search filtered client-side via `searchFilter` — the API has no name-search) — ✅ synced |
| **One Piece** | punk-records dataset (`english/index/cards_by_id.json`) | ✅ generic config, added 2026-08 (4,672 cards, official Bandai CDN art) — ✅ synced |
| **Star Wars: Unlimited** | swu-cards-json dataset (`data/v1/all-cards.json`) | ✅ generic config, added 2026-08 (9,058 cards, official FFG CDN art — note: 53 MB catalog) — ✅ synced |
| **Union Arena** | union-arena-tcg-data (`cards/en/general.json`) | ✅ generic config, added 2026-08 (541 cards, official Bandai CDN art; rarity codes stay as codes — c/u/r/sr/ur + ★ variants) — ✅ synced (363 rows in DB; catalog has 541, some share artwork) |
| **Flesh and Blood** | the-fab-cube dataset (`json/english/card-flattened.json`) | ✅ generic config, added 2026-08 (16,264 printings, image_url fields on Google Storage/S3/CloudFront — fabdb.net unreachable but its CDNs are not) — ✅ synced (16,240 rows) |
| **Pokémon TCG Pocket** | flibustier database + exchange images | ✅ generic config, added 2026-08 (3,761 cards, images resolve from the companion pokemon-tcg-exchange repo) — ✅ synced (3,761 rows) |
| **Altered TCG** | PolluxTroy0/Altered-TCG-Card-Database (repo art via raw.githubusercontent) | ✅ dataset import, added 2026-08 — 3,464 cards (search/hydration via local-DB adapter, no live API) |
| **Force of Will** | Niebvelungen/TCG-Arena-FoW (`fowsim.s3.amazonaws.com` art) | ✅ dataset import, added 2026-08 — 7,272 cards (local-DB adapter) |
| **Duel Masters** | Latepate64/duel-masters-json + Fandom wiki CDN art | ✅ dataset import, added 2026-08 — 1,248 printings (local-DB adapter) |
| **Weiss Schwarz** | JonahSMS/Weiss-Sim-Card-Data (repo scans via raw.githubusercontent) | ✅ dataset import, added 2026-08 — 581 cards (local-DB adapter) |

All games' `card_data` is populated (**15 games**, API games synced with status
`idle`; dataset games imported via `scripts/import-cardset.ts`), so library
browsing, detail hydration, and bundle/chase CSV exports work fully offline.
Live counts: MTG 54,126 · Pokémon 21,775 · Yu-Gi-Oh! 14,478 · FAB 16,240 ·
FoW 7,272 · SWU 9,051 · Altered 3,464 · One Piece 4,672 · Digimon 4,373 ·
Pokémon Pocket 3,761 · Lorcana 2,686 · DM 1,248 · Gundam 1,816 · Weiss 581 ·
Union Arena 363.

For a new game: create the game row (key must match the config's `key`:
`yugioh`, `digimon`, …), then run its sync once (bulk embed, one-time).

## No-API games: dataset import path

One Piece, Dragon Ball Super/Fusion World, and Flesh and Blood currently have
**no clean, hosted, public JSON API** (verified 2026-08 — optcgdb's API gateway
rejects direct access, official sites have no API, dbscards is a static site,
fabdb unreachable). Community sources distribute these games' card lists as
**data files** instead. The dataset importer bridges that gap:

```bash
cd packages/server
npx tsx --env-file ../../.env scripts/import-cardset.ts \
  <gameKey> <path/to/cards.json> [--map mapping.json] [--limit N]
```

Each card is normalized via a small field-mapping file (or common field-name
defaults), embedded with the local SigLIP model, and stored in `cards` with
full card data — search, binning, and bundles then work offline exactly like
the synced games. Verified end-to-end with a real YGOPRODeck export.

To onboard One Piece or DBZ: obtain a trustworthy dataset file (the community
sources are in flux — ask your local card community which one they trust, or
I can research a specific candidate on request), write the ~5-line mapping,
run the importer once.

## Top 20 TCGs and their data-source status

Ranked roughly by 2025–26 market presence; exact order shifts quarterly and
the list past #15 is contested — what matters is the config architecture makes
each of these a small, independent addition.

| # | Game | Data source | Effort |
| --- | --- | --- | --- |
| 1 | Pokémon | TCGdex | ✅ done |
| 2 | Magic: The Gathering | Scryfall | ✅ done |
| 3 | Yu-Gi-Oh! | YGOPRODeck | ✅ done |
| 4 | One Piece Card Game | punk-records GitHub dataset (official Bandai art) | ✅ done (2026-08) |
| 5 | Dragon Ball Super / Super Fusion World | community sites (dbscards); no official API | dataset import (see above) |
| 6 | Disney Lorcana | lorcana-api.com (community API, official Ravensburger artwork) | ✅ done (2026-08) |
| 7 | Flesh and Blood | fab-cube dataset (`image_url` fields — fabdb.net itself unreachable, CDNs work) | ✅ done (2026-08, 16,240 printings synced) |
| 8 | Digimon | digimoncard.io | ✅ done |
| 9 | Star Wars Unlimited | swu-cards-json dataset (official FFG art) | ✅ done (2026-08) |
| 10 | Cardfight!! Vanguard | no reliable public API | source research needed |
| 11 | Gundam | gundam-gcg.com | ✅ done |
| 12 | Weiss Schwarz | Weiss-Sim-Card-Data (EN scans, `CardData.txt`) | ✅ done (2026-08, 581 cards) |
| 13 | Union Arena | union-arena-tcg-data dataset (official Bandai art) | ✅ done (2026-08) |
| 14 | Final Fantasy TCG | community deck sites; no clean API | source research needed |
| 15 | Hololive Official Card Game | no public API | source research needed |
| 16 | Shadowverse Evolve | sim-client data exists, no image URLs | source research needed |
| 17 | Altered TCG | Altered-TCG-Card-Database (repo art) | ✅ done (2026-08, 3,464 cards) |
| 18 | Duel Masters | duel-masters-json + Fandom wiki art | ✅ done (2026-08, 1,248 printings) |
| 19 | Force of Will | TCG-Arena-FoW (`fowsim.s3.amazonaws.com` art) | ✅ done (2026-08, 7,272 cards) |
| 20 | Dragon Ball Z (2008–) | (see Dragon Ball Super) | — |

Notes:
- Games with **no official API** need a community-maintained bulk JSON (cards +
  images + rarity). That source is the research step; once found, the config
  lands in a day (mapping + verify + sync).
- **Foil identity**: DBZ, One Piece, and Digimon have foil/parallel variants
  that are *different product IDs*. The bulk source must list both variants;
  holo detection (scan light) then feeds card identity, not just a badge.
- **Rarity normalization**: each game's rarity codes differ (MTG
  common/uncommon/rare/mythic, YGO Common→Ghost Rare, Digimon c/u/r/sr/sec,
  One Piece C/UC/R/SR/SEC…). The `games.field_definitions` (web UI) maps each
  game's codes onto the bin rules, so bundle recipes work identically.

## Multi-language cards

**Scanning foreign-language cards works today** — the vision matcher (SigLIP)
compares artwork, not text, so a Japanese/French/German printing of a card
with the same art embeds close to the English row and matches. Verified
2026-08-08 with a Japanese MTG printing: cosine distance 0.25 vs the English
row (match threshold 0.30). No interface changes needed — the app stays
English; foreign cards just identify correctly.

**Localized names** are stored per card when the data source provides them
cheaply, and the Library search matches them (search "Dracaufeu" to find
Charizard):

| Game | Localized names | Source |
| --- | --- | --- |
| Pokémon | ✅ fr/de/es/it/pt (20,222 cards) | TCGdex per-locale list endpoints (cheap: one paginated list per locale, no per-card fetches) |
| Altered TCG | 🟡 possible (not imported) | The dataset repo ships per-language card files (CARDS/FR, /DE, /ES, /IT) + per-language art (`allImagePath`); the EN import could be extended |
| MTG | ❌ | Scryfall `unique_artwork` bulk omits `foreign_data`; switching bulk files would change dedupe semantics |
| Yu-Gi-Oh! | ❌ | YGOPRODeck removed its localized name fields (`frname`/`dename`/…) from the API (verified 2026-08) |
| Others | ❌ | Dataset sources ship English only |

Where a source starts shipping localized names, populate them the same way:
add the field to the config's `toCard()` (`card.names`, BCP-47 keys) and
re-run `packages/server/scripts/backfill-localized-names.ts` to update
existing rows without re-embedding.

## Recommended next games

**Live tracker with per-game actions:** `custom/TCGS_ROADMAP.md` — what's
integrated, what's blocked, and what to do to unblock each remaining game.

**Integrated 2026-08 (all verified live):** the 11 API games + 4 dataset games
(Altered 3,464 · FoW 7,272 · Duel Masters 1,248 · Weiss 581) = **15 games**,
all searchable from the Library.

Still needing a data source (all re-verified 2026-08; the blocker is almost
always **images** — a dataset without art can't feed the embedding pipeline):

| Game | Status / blocker |
| --- | --- |
| Dragon Ball Super / Fusion World | images-only repo found (`TCG-Arena-DBSFW`), no metadata JSON; `dbscards.com` static |
| Cardfight!! Vanguard | no dataset with images found (community API stores its DB in Firestore) |
| Final Fantasy TCG | ffdecks is a SPA; API not trivially exposed (check DevTools → Network) |
| Hololive | fan databases only, no stable image-bearing JSON |
| Shadowverse Evolve | sim-client data has English names but **no image URLs**; official CDN pattern not found |
| WIXOSS | JP-only dataset (736 cards), no images |
| My Hero Academia / Warhammer 40K / Buddyfight | no image-bearing dataset on GitHub yet |
| MetaZoo | discontinued |

## Future: TCGplayer integration (digitize → price → list)

Investigation summary (2026-08) — this is a **plan**, not yet built. It pairs
with the scanner's **Digitize mode**: bulk-record cards, then turn that record
into priced, listable inventory.

### What the API offers (v1.39, verified)

| Area | Endpoints | Notes |
| --- | --- | --- |
| **Catalog** | categories / groups (sets) / products / SKUs / GTIN lookup / category search | Products = a unique printing; SKUs = product × condition. Search is the matching path (name + set + collector #). |
| **Pricing** | market price by product/SKU/group, buylist prices | Per-request, key-gated — **no bulk price dump** like Scryfall; needs an on-demand cache |
| **Inventory** | product lists (digital buylists) | |
| **Stores** | seller inventory (SKU qty/prices, batch updates), orders, order manifests, customers, shipping | Order manifest ≈ Roca's “Sort to Ship” |

### Requirements / blockers

1. **API keys — currently unobtainable for new accounts.** The API is
   key-gated (public/private key → bearer token, v1.39 verified from the
   official docs). TCGplayer is **no longer granting new API access**
   (official docs, verified 2026-08 — "We are no longer granting new API
   access at this time"), so a new seller account cannot apply for keys.
   The only path forward via the API is an account that already holds keys
   from before the freeze. Everything below stays valid for when access
   reopens.
2. **Product/SKU matching.** Every synced card must be matched to a TCGplayer
   productId (then SKUId by condition). A “match to TCGplayer” sync job
   (name + set + collector number → catalog search → store productId) is the
   biggest chunk of work and the accuracy risk.
3. **Prices are per-request** — cache them (same pattern as the art cache:
   on-demand lookup, store `price_updated_at`, refresh daily).
4. **Condition grading** — TCGplayer sells by condition (Near Mint, Lightly
   Played…). Our scans don't grade; the operator sets a default condition
   (usually NM) per export.

### Suggested roadmap (low-friction first)

1. **Bulk-inventory CSV export (no API needed) — ✅ built.** The “TCGplayer
   CSV” export from a collection/digitize session — SKU-free but TCGplayer's
   portal accepts name/set/number + quantity + price + condition uploads for
   manual listing. This is the 80/20 win and needs zero API access. Also note
   the app already prices MTG + Yu-Gi-Oh! without the TCGplayer API:
   Scryfall carries TCGplayer market prices for MTG, and YGOPRODeck's
   `tcgplayer_price` field *is* the TCGplayer market price.
2. **Price source adapter:** with API keys, a `tcgplayer` price source in the
   same family as Scryfall/YGO — fills `prices.usd` for value rules + bundle
   value, cached per card. (Parked until keys exist.)
3. **Catalog match job:** resolve every synced card to a productId/SKUId and
   persist it (one-time per game, then incrementally for new sets).
4. **Full automation (optional):** store inventory sync (prices/qty via batch
   endpoints), order manifest → sort-to-ship using our bundle/chase data.

Revisit when TCGplayer reopens API applications (or an existing-key account
is available) — the scanner side (digitize mode) is already built so the
integration is additive.

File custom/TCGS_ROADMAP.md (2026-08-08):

# TCG integration roadmap & data-source tracker

**Goal: 20 functioning, currently-popular TCGs.** A game is "functioning" when
its game row exists, the adapter can search, and the sync can populate the
card database with **images** (images are the hard requirement — the SigLIP
embedding pipeline can't work without card art).

**Current count: 15 integrated (11 synced + 4 dataset-imported), all searchable** (status `idle` verified 2026-08).
Adding a game = one config in
`packages/server/src/lib/card-search/generic-configs.ts` + registration in
`resolve.ts` / `sync-job.ts` / the image allowlist in `routes/card.ts` + a seed
row in `packages/server/scripts/seed-local.ts`. The seeder is idempotent
(`cd packages/server && npx tsx --env-file ../../.env scripts/seed-local.ts`).

## ✅ Integrated (11)

| # | Game | Source | Cards | Images | Sync |
| --- | --- | --- | --- | --- | --- |
| 1 | MTG | Scryfall | 54,009 | ✅ | ✅ done |
| 12 | Altered TCG | Altered-TCG-Card-Database | 3,464 | ✅ | ✅ imported |
| 13 | Force of Will | TCG-Arena-FoW | 7,272 | ✅ | ✅ imported |
| 14 | Duel Masters | duel-masters-json + Fandom | 1,248 | ✅ | ✅ imported |
| 15 | Weiss Schwarz | Weiss-Sim-Card-Data | 581 | ✅ | ✅ imported |
| 2 | Pokémon | TCGdex | 21,756 | ✅ | ✅ done |
| 3 | Yu-Gi-Oh! | YGOPRODeck | 14,477 | ✅ | ✅ done |
| 4 | Digimon | digimoncard.io | 4,373 | ✅ | ✅ done |
| 5 | Gundam | gundam-gcg.com | 1,816 | ✅ | ✅ done |
| 6 | Union Arena | apitcg/union-arena-tcg-data | 541 | ✅ | ✅ done |
| 7 | Disney Lorcana | lorcana-api.com | 2,694 | ✅ | ✅ done |
| 8 | One Piece | buhbbl/punk-records | 4,672 | ✅ | ✅ done |
| 9 | Star Wars: Unlimited | Team-Zura/swu-cards-json | 9,058 | ✅ | ✅ done |
| 10 | Flesh and Blood | the-fab-cube/flesh-and-blood-cards | 16,264 printings | ✅ | ✅ done (per-printing rarity) |
| 11 | Pokémon TCG Pocket | flibustier/pokemon-tcg-pocket-database | 3,761 | ✅ | ✅ done |

Notes: FAB images come from the dataset's `image_url` fields (Google
Storage/S3/CloudFront CDNs — fabdb.net itself is unreachable from this
machine, but its CDNs are not). FAB syncs **one row per printing**
(`printing_unique_id`), so a card reprinted across sets keeps its per-set
rarity and art — cards with identical art across printings embed the same
(scan matching picks any row; the rarity shown is that printing's).
SWU/FAB catalogs are 39–53 MB, so the first search per 15-min cache window
is slow; Pocket images resolve 1:1 from the companion pokemon-tcg-exchange
repo. Pokémon rows carry localized names (fr/de/es/it/pt) — see `TCGS.md`
"Multi-language cards".

## 🎯 Remaining target games — deep research (verified 2026-08)

Each row lists the best source options found, what's blocking, and a concrete
**action you can take**.

| Game | Source options found | Blocker | What to do |
| --- | --- | --- | --- |
| **Dragon Ball Super** | Official `en.dbs-card.com` (has a card DB with art) | Unreachable from this machine (connection fails — likely geo/WAF); `dbscards.com` is a static GoDaddy site; no GitHub dataset with images found | Try `en.dbs-card.com` from another network/VPN and open its card list — if it loads, I can scrape it into a dataset. Check the JP site `dbs-card.com`. Ask the DBS Discord/Reddit for a maintained JSON export |
| **Cardfight!! Vanguard** | Official `en.cf-vanguard.com` (responds, but root/cardlist 404 from here) | Region/WAF path-gated; no GitHub dataset with images found | Browse the official site in a browser to find the working card-DB URL (I need just the real path), or find a community dataset on the Vanguard Discord |
| **Weiss Schwarz** | Official `en.ws-tcg.com` (responds, root 404); only per-anime-series sim data on GitHub (JonahSMS/Weiss-Sim-Card-Data — fragmented, no unified EN catalog) | No unified image-bearing EN catalog found | Same as Vanguard: find the official card-list URL, or a community "all sets" JSON. The sim data could be merged if images are added |
| **Final Fantasy TCG** | `ffdecks.com` (deck site, SPA — may have an internal API); official `ff-tcg.com` unreachable from here | No dataset found | Open ffdecks.com and check DevTools → Network for a JSON cards endpoint; report the URL and I'll wire it |
| **Hololive OCG** | Fan DBs (H2KFORGIVEN/hololive-cardgame-fanmade; ChinGuang/hololive-tcg-model) | Fan sites are interactive, no stable image-bearing JSON verified | Check the fan practice site's network requests for a card JSON + image CDN |
| **Shadowverse Evolve** | anthonychian/shadowverse-client (33★ simulator — card data lives in its `server/` or `api/` dir) | Data is embedded in app code, not shipped as a clean JSON | Clone the repo and look for a cards JSON/SQL dump; if found, I'll map it |
| **Altered TCG** | PolluxTroy0/Altered-TCG-Card-Database (per-set, per-faction files + an IMAGES dir); official `api.altered.gg` dead | Fragmented — no single combined file or verified image URL pattern | If you want it, I can consolidate the per-set JSON + image dir into a single dataset file (needs a one-time local build step) |
| **Duel Masters** | Latepate64/duel-masters-json (26★ — complete data) | **No image URLs** in the dataset; no reachable image host found | Find the official/community image CDN (dm-wiki, takaratomy) and give me the URL pattern — data side is ready |
| **WIXOSS** | yyasakura/WIXOSS-CARDS-JSON (tiny, unverified) | Unverified quality; no images | Only worth it if you care about WIXOSS; verify the dataset + find images |
| **Battle Spirits** | None (JP-only) | No English source | Skip unless you're building a JP-focused rig |

## 🚫 Skipped (per earlier analysis)

MetaZoo (discontinued), Legend of the Five Rings (not booster-based), Warhammer
40K TCG / Bakugan (different formats), One Piece's `optcg-api` REST API
(key-gated — **free on request**, would add prices + fresher data if you want
to email the author per that repo's README).

## 🔧 Finding the "needed parts" — general playbook

1. **Images are the gate.** A dataset without art is useless to us. If you find
   a card *list*, look for its image CDN (often `cdn.<game>.com` or
   `storage.googleapis.com`). One working image URL = a pattern I can use for
   the whole game.
2. **Official sites that block this machine** (`en.dbs-card.com`,
   `en.cf-vanguard.com`, `en.ws-tcg.com`, `ff-tcg.com`) often work from a
   phone/browser/VPN. Just get me the real card-list URL and whether images are
   predictable — I'll handle the rest (including a scraper if needed).
3. **Community datasets:** game-specific Discords/Reddits usually have someone
   maintaining a JSON export (that's where punk-records, swu-cards-json, and
   fab-cube came from). Ask for "card data + images JSON" — most maintainers
   are happy to share.
4. **The Wayback Machine** (`web.archive.org`) can surface old card-DB pages
   and their API paths if a site changed.
5. **Keep the tracker honest:** every claim above was verified by direct
   probing on this machine today (2026-08). When you take an action, update the
   row — I can re-verify and integrate the moment a source becomes available.

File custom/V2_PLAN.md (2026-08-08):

# DeckSift v2 Plan — hardened commercial roadmap

**Date:** 2026-08-08 · **Author:** lead engineer · **Status:** living plan, supersedes the roadmap sections of `PLAN.md` / `PRODUCT.md` / `HARDWARE_V2.md` where they overlap; those remain the detailed references.

## How this plan was built

This plan synthesizes every planning input in the repo into one phased, gated
roadmap. Sources are tagged inline so a reader can go to the original:

- **[R]** `custom/RESEARCH_MARKET.md` — market research (segments, competitors, ranked wants, pain points, §6 wishlist)
- **[H]** `custom/HARDWARE_V2.md` — production-leaning hardware review + phases 0–5 + §7 measurement gate
- **[P]** `custom/PRODUCT.md` — v1 home → v2 commercial product tiers and backlog
- **[T]** `custom/TCGS.md` + `custom/TCGS_ROADMAP.md` — TCG expansion to 20 games, TCGplayer API roadmap
- **[F]** `custom/PLAN.md` — firmware roadmap (largely shipped; commissioning checklist still open)
- **[I]** implementation agent's flags (Items 63–65, `custom/CHANGES.md`)
- **[QA]** `custom/QA_REPORT.md` — independent review + residual observations

**The core discipline (unchanged from `HARDWARE_V2.md §7`):** every hardware
decision is gated on a *measured number*, not enthusiasm. Software ships first,
the single machine is commissioned and measured, and only then does money go to
v2/farm hardware.

---
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

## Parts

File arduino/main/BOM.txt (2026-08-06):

==========================================================================
 DECK SIFT  -  BILL OF MATERIALS  (v1 card sorter)
==========================================================================
 One hopper-fed, Arduino/ESP32-driven card sorter that routes cards into
 seven bins. Print this page and tick items off as you buy them.

 Print the parts first: 3d model/card_sorter.3mf (slicer-ready mesh) or
 card_sorter_decksift.3mf (DeckSift's revised parts). The Fusion 360
 source is 3d model/Card Sorter.f3d.

--------------------------------------------------------------------------
 CONTROLLER (pick ONE)
--------------------------------------------------------------------------
 [ ]  1   Arduino Uno R4 Minima (ABX0080)      - original reference board
 [ ]  1   ESP32-S3 DevKit (CH340/CH343 or      - DeckSift's primary; native
           native-USB type)                      USB or bridge - see
                                                 arduino/main/CONTROLLERS.md
                                                 for logic-level wiring

--------------------------------------------------------------------------
 ELECTRONICS
--------------------------------------------------------------------------
 [ ]  1   PCA9685 16-channel 12-bit PWM/servo driver (I2C, all 10 servos)
 [ ]  9   SG90 (or MG90S) micro servo, positional 180 deg
          (3 per module: bottom trapdoor, paddle gate, pusher)
 [ ]  1   SG90 servo, modified for CONTINUOUS rotation (the feeder)
 [ ]  1   White 5 mm LED + 100-220 ohm resistor (scan light, optional but
          recommended for holo detection) - PCA9685 ch0 / firmware LED 1
 [ ]  3   Status LEDs + resistors (optional): green (ch1), red (ch2),
          orange (ch3) - operating / fault / comms lamps

--------------------------------------------------------------------------
 SENSING
--------------------------------------------------------------------------
 [ ]  4   Reflective/obstacle IR sensor modules, 3-pin
          (VCC, GND, digital OUT) - module gates 1-3 + hopper throat
          NOTE on 3.3 V boards (ESP32-S3/Pico/STM32): use 3.3 V modules
          or a voltage divider - their GPIOs are NOT 5 V tolerant

--------------------------------------------------------------------------
 POWER
--------------------------------------------------------------------------
 [ ]  1   5 V regulated power supply, 4-10 A (the servo bus - do NOT run
          10 servos off the board's USB 5 V)
 [ ]  1   DC barrel jack or screw-terminal pigtail for the PSU
 [ ]  1   USB cable for the controller (USB-A-to-USB-C for the R4; the
          ESP32-S3 dev kit's own cable)

--------------------------------------------------------------------------
 STRUCTURAL / PRINTED
--------------------------------------------------------------------------
 [ ]  -   PLA or PETG filament (per your slicer's estimate)
 [ ]  6   G20 o-ring (feeder roller grip)

--------------------------------------------------------------------------
 FASTENERS & WIRING
--------------------------------------------------------------------------
 [ ] 22   M3 x 6 screws (14 = bin bases to housing; 8 = base panels to base)
 [ ]  8   M3 nuts (base panel screws)
 [ ]  2   M3 x 8 screws (hopper tube)
 [ ] 33   M2 x 4 screws, 11 per module (flappers, pusher arms, IR mounts)
 [ ]  8   M2 x 6 screws (Arduino + PCA9685 to base panels)
 [ ] 10   servo horn screws (included with the servos)
 [ ]  1   roll 22-26 AWG hookup wire (IR sensors)
 [ ] ~50  Dupont connectors (only if adding connectors to IR wires)

--------------------------------------------------------------------------
 TOOLS (already have?)
--------------------------------------------------------------------------
 [ ]     Small Philips screwdriver set
 [ ]     Soldering iron + solder (IR sensor wires, LED + resistor joints)
 [ ]     Wire strippers / flush cutters
 [ ]     Zip ties / cable management (optional)

--------------------------------------------------------------------------
 NOTES
--------------------------------------------------------------------------
 * Common ground is MANDATORY: PSU GND -> PCA9685 GND -> controller GND.
 * The PCA9685 logic VCC is 5 V on the Uno R4, 3.3 V on ESP32-S3/Pico/STM32.
 * Servo signals stay 5 V via the PCA9685's V+ rail on every board.
 * Bulk capacitance (1000-2200 uF) across the servo rail is cheap insurance.
 * Full wiring + per-board details: arduino/main/BUILD.md, CONTROLLERS.md
 * The scan light wiring: LED anode -> PCA9685 ch0 pin (via resistor),
   cathode -> GND (the PCA9685 sinks current).

==========================================================================

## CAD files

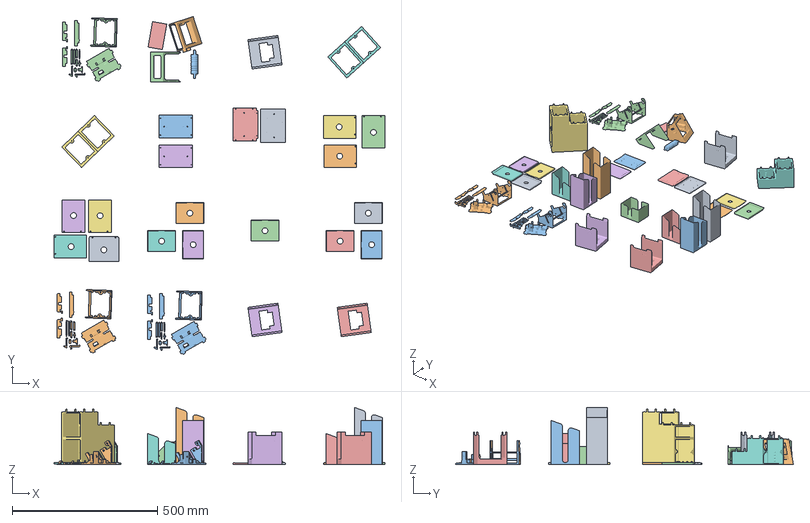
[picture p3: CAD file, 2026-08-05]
3d model/card_sorter_decksift.3mf
1138.7 x 1163.7 x 197.3 mm
card_sleeve_lg x 2
card_sleeve_md x 2
card_sleeve_end
card_sleeve_small x 2
generic base wing x 6
arduino base
servo controller base
base_end
generic base
base_back
base_front
shroud x 3
feeder_base
roller
card_tube
card_base_wing_end
Assembly x 3

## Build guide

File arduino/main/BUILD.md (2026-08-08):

# Build guide — DeckSift card sorter

Parts list and assembly instructions for the physical sorting unit: a hopper feeds cards one at a time through three stacked routing modules, each capable of dropping a card into one of two side bins or passing it down to the next module — seven bins total, driven by an Arduino Uno R4 Minima over I²C.

- **Firmware:** `arduino/main/main.ino` — **one universal sketch** for multiple boards (`board-config.h` abstracts EEPROM, I2C pins and interrupts). Tested targets: **Arduino Uno R4 Minima** and **ESP32-S3** (the DeckSift primary going forward — more flash/RAM headroom and native-USB Web Serial). Also compiles for RP2040/Pico and STM32 with no sketch changes.
- **Enclosure:** `3d model/Card Sorter.f3d` (Fusion 360 source) or `3d model/card_sorter.3mf` (mesh, slicer-ready) — the original design by dishwasher-detergent. DeckSift's revised parts live alongside as `3d model/card_sorter_decksift.3mf` — both files are the same machine; use whichever matches your print setup. 3D files are CC BY-NC-SA 4.0 (see `3d model/LICENSE`).
- **Calibration:** `/app/calibrate` in the web app
- **Photo references:** the original interactive guide at [mault.xyz/build](https://mault.xyz/build) shows assembly photos for most steps (`/instructions/*.jpg` in the repo)
- **Print files:** the printable parts are the 3MFs in `3d model/` — `card_sorter.3mf` (original design by dishwasher-detergent) and `card_sorter_decksift.3mf` (DeckSift's revised parts, print-optimized for faster, more efficient batches — 30 parts across 16 plates). Slice either in Bambu Studio/Cura; both are the same machine. The **DeckSift Bambu print kit** (`3d model/kit/`) has a tick-box quantity sheet + the 16-plate plan for `card_sorter_decksift.3mf`.
- **Shopping list:** print **`BOM.txt`** (this folder) and tick items as you buy them.

---

## 1. Bill of materials

Quantities match the firmware exactly — 3 modules × 3 servos, 1 feeder, 4 IR sensors, and the PCA9685's 16 channels: 10 servos, 4 LED channels (0–3), and channel 14 for the optional scan light.

### Electronics

| Qty | Part | Notes |
| --- | --- | --- |
| 1 | White LED + 100–220 Ω resistor (scan light) | Optional but recommended for holo detection — wired to PCA9685 ch0 (firmware LED 1). See “Scan light” wiring below. |
| 1 | Arduino Uno R4 Minima (ABX0080) | Runs `main.ino`; USB connection to the host computer for Web Serial |
| 1 | Adafruit PCA9685 16-channel 12-bit PWM/servo driver | I²C servo driver — drives all 10 servos |
| 9 | SG90 micro servo, positional (180°) | 3 per module × 3 modules — bottom trapdoor, paddle gate, pusher |
| 1 | SG90 servo, modified for continuous rotation | Feeder — drives cards out of the hopper into module 1 |

### Sensing

| Qty | Part | Notes |
| --- | --- | --- |
| 4 | Reflective/obstacle IR sensor module (3-pin: VCC, GND, digital OUT) | One at the gate of modules 1, 2, 3, plus one in the hopper throat |

### Power

| Qty | Part | Notes |
| --- | --- | --- |
| 1 | 5 V regulated power supply, 4–10 A | Dedicated servo bus power into the PCA9685 `V+` terminal — **do not power 10 servos off the Arduino's onboard 5 V** |
| 1 | USB-A–to–USB-C cable | Arduino Uno R4 Minima ↔ host computer |
| 1 | DC barrel jack or screw-terminal pigtail | Adapts the PSU output to the PCA9685's `V+` / `GND` terminal |

### Structural

| Qty | Part | Notes |
| --- | --- | --- |
| 1 set | 3D-printed enclosure & module housings | Print from `card_sorter.3mf` (mesh, slicer-ready) or `Card Sorter.f3d` (Fusion 360 source) |
| — | PLA or PETG filament | Quantity per your slicer's estimate for the model above |
| 6 | G20 o-ring | Fitted onto the feeder roller for grip on the card face |

### Fasteners & wiring supplies

| Qty | Part | Notes |
| --- | --- | --- |
| 22 | M3×6 screw | 14 attach each bin base to the housing; 8 attach the base panels to the base |
| 8 | M3 nut | Paired with the base panel M3×6 screws |
| 2 | M3×8 screw | Attaches the hopper tube |
| 33 | M2×4 screw (11 per module) | Per module: flapper (bottom/sides), pusher arms, and IR sensor mounts |
| 8 | M2×6 screw | Mounts the Arduino and PCA9685 servo driver board to the base panels |
| 10 | Servo horn screw (included with servos) | Secures the horn to the shaft |
| 1 roll | 22–26 AWG hookup wire | IR sensor wiring |
| ~50 | Dupont connectors | Only needed if connecting your own connectors to the IR sensor wires; otherwise solder directly to the sensor pads |

---

## 2. Wiring

Everything hangs off one I²C bus (PCA9685) and four digital input pins (IR sensors). The PCA9685's logic side runs off the Arduino's 5 V; its `V+` servo rail must come from the external supply, and **that supply's ground must be tied back to the Arduino's ground** — a floating servo ground is the most common reason a freshly wired unit won't move.

> **ESP32-S3 (DeckSift's primary controller):** the tables below show the Uno
> R4 reference wiring. For the ESP32-S3-DevKitC-1, see
> **[`WIRING_S3.md`](WIRING_S3.md)** — pin-by-pin header layout, 3.3 V logic
> rules, and the exact GPIO numbers (`board-config.h` defaults). The logic
> supply on the S3 is **3.3 V** (never 5 V into a GPIO).

### I²C bus

| PCA9685 pin | Arduino Uno R4 Minima |
| --- | --- |
| `SDA` | `SDA` |
| `SCL` | `SCL` |
| `VCC` (logic) | `5V` |
| `GND` | `GND` |

### Servo power

| From | To |
| --- | --- |
| External 5 V PSU, `+` | PCA9685 `V+` terminal block |
| External 5 V PSU, `−` | PCA9685 `GND` terminal block **and** Arduino `GND` |

### IR sensors

All four read **active-LOW** (pin goes low when a card is present) using the Arduino's internal pull-up — wire the sensor's digital `OUT` straight to the pin, no external pull-up resistor needed.

| Sensor | Arduino pin |
| --- | --- |
| Module 1 gate | `D2` |
| Module 2 gate | `D3` |
| Module 3 gate | `D4` |
| Hopper throat | `D5` |

### PCA9685 channel map

| Ch. | Assignment |
| --- | --- |
| 0 | **LED 1 — scan light** (firmware `{"led":1,"on":bool}`) — angled holo-detection light |
| 1 | LED 2 — green “operating” indicator (firmware-driven) |
| 2 | LED 3 — red “machine fault” indicator (firmware-driven) |
| 3 | LED 4 — orange “software/comms fault” indicator (firmware-driven) |
| 4 | Module 1 — bottom |
| 5 | Module 1 — paddle |
| 6 | Module 1 — pusher |
| 7 | Module 2 — bottom |
| 8 | Module 2 — paddle |
| 9 | Module 2 — pusher |
| 10 | Module 3 — bottom |
| 11 | Module 3 — paddle |
| 12 | Module 3 — pusher |
| 13 | Feeder (continuous rotation) |
| 14 | Spare |
| 15 | Spare |

### Scan light

The scan light is a white LED mounted at an **angle to the card** (roughly
30–45° off the camera axis) so its reflection grazes the foil surface. The web
app toggles it (firmware LED 1 / PCA9685 ch0) between two captures: a frame
with the light off, then a frame with it on. Holo cards change **color**
between the frames (diffraction grating); matte cards only get brighter. The
light-on frame is also the better-lit image for card matching itself.

Wiring (PCA9685 outputs are open-drain — they sink current, so the LED sits
between `V+` and the channel pin):

| From | To |
| --- | --- |
| PCA9685 `V+` | LED anode (via 100–220 Ω resistor) |
| PCA9685 ch14 (`OE`-side output) | LED cathode |

A single high-brightness white LED is fine on the channel directly (≈25 mA).
For a bigger light bar, drive it through a small N-channel MOSFET on the same
pin. Keep the LED beam off the camera lens to avoid glare in the scan region.

---

## 3. Assembly

Eight phases, structural work first.

### Phase 1 — Print the structural parts

1. Slice and print the enclosure and three module housings from `card_sorter.3mf` (or re-export from `Card Sorter.f3d`).
   - PLA is fine for the housings; PETG if the unit will sit somewhere warm.
2. Dry-fit each module housing before inserting any electronics — sand or adjust any tight servo pockets now. *(Photos: `top_down_view_device.jpg`, `corner_view_device.jpg`, `front_view_device.jpg`)*
3. Mount the Arduino and PCA9685 servo driver board to the base panels with 8 M2×6 screws.
4. Attach the base panels to the base with 8 M3×6 screws and 8 M3 nuts.
   - Do this **after** the Arduino and PCA9685 are mounted to the panels — the boards are much harder to reach once the panels are on the base.

### Phase 2 — Mount the servos

1. Install the bottom, paddle, and pusher servo into each of the 3 module housings (9 servos total).
   - Center each servo at its neutral pulse before screwing down the horn, so mechanical range matches the firmware's open/closed travel. *(Photo: `top_down_view_module.jpg`)*
2. Attach the bottom flapper to the bottom servo's horn with M2×4 screws, servo held at its closed pulse so the flapper seats flush across the card path.
   - This is the trapdoor a card falls through to reach the next module, or the current one on a match. *(Photo: `bottom_paddle.jpg`)*
3. Before attaching anything, command each paddle servo through its full range to confirm the linkage can reach fully open without binding. Then, with the servo held at its closed position, attach the left and right flapper to the shared linkage with M2×4 screws (one pair per module) so both sit flush and even.
   - One paddle servo drives both flappers together — they open and close as a pair, not independently. Fit the flappers closed first; the exact open-position pulse gets fine-tuned later from the Module Calibration Grid. *(Photo: `side_paddles.jpg`)*
4. Before fitting the arm, sweep the pusher servo through its full left-to-right range and find its true mechanical middle. With the servo held at that middle position, attach the card pusher arm to the horn with M2×4 screws so it sits centered between the left and right bins.
   - Fitting the arm off-center biases the push distance to one side — the exact left/right pulses get fine-tuned later from the Module Calibration Grid. *(Photo: `pusher_arms.jpg`)*
5. Fit 6 G20 o-rings onto the feeder roller.
   - These give the roller grip on the card face — space them evenly along the roller's length.
6. Attach the roller to the feeder module. *(Photo: `feeder_roller.jpg`)*
7. Install the continuous-rotation feeder servo to the roller, at the base of the hopper. *(Photo: `feeder_servo.jpg`)*
8. Attach the wall piece to the tube that guides cards from the hopper to the feeder roller.
   - When mounting the wall, attach it to the feeder module first, then put 2 cards below the wall and slide it down before tightening it into place. *(Photo: `feeder_tube_wall.jpg`)*

### Phase 3 — Mount the IR sensors

1. Fix one IR sensor at the gate of each module (1, 2, 3), aimed across the card path. *(Photo: `ir_sensor.jpg`)*
2. Fix the fourth IR sensor in the hopper throat, just above the feeder.
   - This one tells the feeder when the hopper is empty — placement matters more than the module sensors.

### Phase 4 — Wire the electronics

1. Wire the PCA9685 to the Arduino's I²C bus (`SDA`/`SCL`) and `5V`/`GND` for logic power. (See Wiring section above.)
2. Wire all 10 servos into PCA9685 channels 0–13 per the channel map.
   - There are wire channels, that use zip ties, in the side of the base to help keep everything neat.
3. Wire the 4 IR sensors to `D2`–`D5`.
   - For the power and ground, you will have to combine 4 wires into one, either with a breadboard or by twisting and soldering them together.
4. Bring the external 5 V supply into the PCA9685 `V+`/`GND` terminal, and tie its ground to the Arduino's ground.
   - Skipping the common ground is the #1 cause of servos that twitch but never move correctly.

### Phase 5 — Flash the firmware

1. In the Arduino IDE, install the **ArduinoJson** and **Adafruit PWM Servo Driver** libraries (Library Manager → search each by name).
2. Select board **Arduino Uno R4 Minima**, select the correct port, then upload `arduino/main/main.ino`.
3. Open the Serial Monitor at 9600 baud and confirm you see `{"status":"ready"}` after the board resets.

### Phase 6 — First power-on test

1. With the external servo supply connected, send `{"test": true}` over serial.
   - Cycles every bottom and paddle open, sweeps all pushers left then right, resets to neutral, then briefly spins the feeder.
2. Watch each module during the test — confirm nothing binds or grinds at the end of its travel.
   - If a servo strains at open or closed, its housing cutout likely needs adjusting before calibration.

### Phase 7 — Calibrate from the app

1. Connect the Arduino to the app via Web Serial, then open `/app/calibrate`.
2. **Module Calibration Grid** — set the open/closed pulse for each bottom and paddle, and left/neutral/right for each pusher, module by module.
3. **Feeder Calibration Panel** — tune feed speed, pulse/pause timing, and settle duration against your actual hopper.
4. **IR Sensor Panel** — verify all 4 sensors report present/absent correctly with a card in hand.
5. **Bin Routing Controls** — send a test card to each of the 7 bins in turn and confirm it lands correctly.

### Phase 8 — Load and run

1. Load the hopper and confirm the feeder stops pulsing once the hopper IR reads empty.
2. Run a full scan-to-bin pass end to end before leaving the unit unattended.

---

## 4. Firmware default values (for reference)

| Parameter | Default |
| --- | --- |
| Module servo pulses (all modules) | bottom/paddle closed `150`, open `307`; pusher left `150`, neutral `307`, right `460` |
| Feeder config | speed `400`, duration `3000 ms`, pulse `80 ms`, pause `50 ms`, settle `150 ms` |
| Routing delays | card-enter `300 ms`, paddle `300 ms`, push `600 ms` |
| IR wait timeout | `3000 ms` |
| Module 1 jam alert timeout | `20000 ms` |
| PWM clamp (setServoPosition) | `120–490` |

Pulses are calibrated per-installation from the app — the values above are only starting points.

## 5. Webcam (reference, Logitech C920)

Auto Focus: Off · Focus: 50% · Auto Exposure: On · Low Light Compensation: On · Auto White Balance: On · Brightness: 140 · Contrast: 140 · Saturation: 160 · Sharpness: 130

## 6. Need help?

- Interactive guide with photos: https://mault.xyz/build
- Upstream repo & issues: https://github.com/dishwasher-detergent/mault

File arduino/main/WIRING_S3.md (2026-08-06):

# ESP32-S3 wiring — `ESP32-S3-DevKitC-1` (CH343 bridge)

This page is the **DeckSift wiring guide for the ESP32-S3-DevKitC-1** — the
common "ESP32-S3 Dev Module" dev board with a **CH343 USB-serial bridge** and
dual-row 38-pin headers. It is the reference for the ESP32-S3 build of
`main.ino` (DeckSift's primary controller).

> **First, identify your board.** The canonical board is the Espressif
> [ESP32-S3-DevKitC-1](https://docs.espressif.com/projects/esp-idf/en/latest/esp32s3/hw-reference/esp32s3/user-guide-devkitc-1.html)
> (ESP32-S3-WROOM-1 module). Many compatible clones exist — the wiring below
> applies to any board with the same 38-pin DevKitC-1 layout. **The silkscreen
> prints the GPIO number next to every pin — trust the silkscreen over any
> diagram**, including this one.

## Logic levels (read this before anything else)

| Item | Value |
| --- | --- |
| ESP32-S3 I/O | **3.3 V** — feeding 5 V into a GPIO can damage the chip |
| 5 V tolerant inputs? | **NO** |
| Servo signals | 5 V (correct) — the PCA9685 drives its outputs at its `V+` supply, not at logic VCC |
| PCA9685 logic VCC | 3.3 V (from the board's 3V3 pin) |
| IR sensor modules | use **3.3 V-compatible** modules, or a 1 kΩ/2 kΩ divider on their outputs if powered at 5 V |

Full details + per-board comparison: [`CONTROLLERS.md`](CONTROLLERS.md).

## Pin map used by the firmware

`board-config.h` defaults these for ESP32-S3 (all overridable at build time
with `-D<NAME>=n`):

| Macro | GPIO | Used for | DevKitC-1 header |
| --- | --- | --- | --- |
| `IR_PIN_MODULE1` | **GPIO 6** | Module 1 gate sensor (active-LOW) | J1 pin 8 |
| `IR_PIN_MODULE2` | **GPIO 7** | Module 2 gate sensor | J1 pin 9 |
| `IR_PIN_MODULE3` | **GPIO 10** | Module 3 gate sensor | J1 pin 18 |
| `IR_PIN_HOPPER` | **GPIO 11** | Hopper throat sensor | J1 pin 19 |
| `I2C_SDA` | **GPIO 8** | PCA9685 SDA | J1 pin 14 |
| `I2C_SCL` | **GPIO 9** | PCA9685 SCL | J1 pin 17 |

Why these pins: GPIO 0/3/45/46 are strapping pins (affect boot mode) and
GPIO 3 is also JTAG — the defaults work, but 6/7/10/11 avoid **every**
special-function pin and are all interrupt-capable. GPIO 8/9 are plain I²C
pins on the S3 (not to be confused with the ESP32's classic I²C pins).

## DevKitC-1 header layout (38-pin)

Two rows of 19 pins, numbered from the USB end. **J1 is the left row**
(when the USB port faces you, board text upright), **J2 the right row**.

### J1 — left header (top → bottom)

| Pin | GPIO / net | DeckSift connection |
| --- | --- | --- |
| 1 | GND | common ground |
| 2 | 3V3 | PCA9685 VCC (logic) |
| 3 | 5V | — (leave free; logic runs from 3V3) |
| 4 | GND | common ground |
| 5 | GND | common ground |
| 6 | GPIO 4 | — spare |
| 7 | GPIO 5 | — spare |
| 8 | **GPIO 6** | **IR Module 1 → OUT** |
| 9 | **GPIO 7** | **IR Module 2 → OUT** |
| 10 | GPIO 15 | — spare |
| 11 | GPIO 16 | — spare |
| 12 | GPIO 17 | — spare |
| 13 | GPIO 18 | — spare |
| 14 | **GPIO 8** | **PCA9685 SDA** |
| 15 | GPIO 3 | strapping/JTAG — do not use |
| 16 | GPIO 46 | strapping — do not use |
| 17 | **GPIO 9** | **PCA9685 SCL** |
| 18 | **GPIO 10** | **IR Module 3 → OUT** |
| 19 | **GPIO 11** | **IR Hopper → OUT** |

### J2 — right header (top → bottom)

| Pin | GPIO / net | DeckSift connection |
| --- | --- | --- |
| 1 | GPIO 12 | — spare |
| 2 | GPIO 13 | — spare |
| 3 | GPIO 14 | — spare |
| 4 | GPIO 21 | — spare |
| 5 | GPIO 47 | — spare |
| 6 | GPIO 48 | — spare |
| 7 | GPIO 35 | — spare |
| 8 | GPIO 36 | — spare |
| 9 | GPIO 37 | — spare |
| 10 | GPIO 38 | — spare |
| 11 | GPIO 39 | — spare |
| 12 | GPIO 40 | — spare |
| 13 | GPIO 41 | — spare |
| 14 | GPIO 42 | — spare |
| 15 | GPIO 2 | — spare |
| 16 | GPIO 1 | — spare |
| 17 | GPIO 0 | strapping — do not use |
| 18 | RX0 (GPIO 44) | UART0 RX — in use by the USB bridge, do not reuse |
| 19 | TX0 (GPIO 43) | UART0 TX — in use by the USB bridge, do not reuse |

Also on the board: **5V / 3V3 / GND / EN / BOOT** pads at the top near the
USB connector, the **BOOT** and **EN (reset)** buttons, and the bridge USB
port. GPIO 19/20 are the native-USB pins (behind the other USB-C on some
revisions) — don't reuse them as general I/O.

## Full wiring list

### PCA9685 servo driver (I²C)

| PCA9685 pin | Connect to | DevKitC-1 header |
| --- | --- | --- |
| `VCC` | board **3V3** (logic supply, 3.3–5 V OK) | J1 pin 2 |
| `GND` | common ground | J1 pin 1/4/5 |
| `SDA` | **GPIO 8** | J1 pin 14 |
| `SCL` | **GPIO 9** | J1 pin 17 |
| `V+` | **external 5 V PSU (4–10 A)** — the servo rail | — |
| `OE` | GND (enable always on) | — |

### IR sensors (active-LOW, module OUT pulls the pin LOW when a card is present)

| Sensor | OUT → | Power |
| --- | --- | --- |
| Module 1 gate | GPIO 6 (J1 pin 8) | 3.3 V + GND (or 5 V with a divider) |
| Module 2 gate | GPIO 7 (J1 pin 9) | 3.3 V + GND |
| Module 3 gate | GPIO 10 (J1 pin 18) | 3.3 V + GND |
| Hopper throat | GPIO 11 (J1 pin 19) | 3.3 V + GND |

The firmware enables the internal pull-ups, so an open-collector output works
with no extra resistor.

### LEDs — via PCA9685 channels (no GPIOs used)

| Channel | LED | Purpose | Wiring |
| --- | --- | --- | --- |
| ch0 | LED 1 | **Scan light** — angled holo-detection light, toggled by the web app for two-frame foil scans | PCA9685 OUT0 → LED + current-limit resistor (220–470 Ω for an indicator LED) → GND |
| ch1 | LED 2 | Green "operating" | as above |
| ch2 | LED 3 | Red "machine fault" | as above |
| ch3 | LED 4 | Orange "software/comms fault" | as above |

PCA9685 outputs are **open-drain, ~25 mA max** — fine for indicator LEDs and
a small scan LED with a resistor. For a **brighter scan light**, drive it from
the 5 V rail through a small MOSFET (e.g. 2N7000: gate ← ch0 via 220 Ω, drain
← LED−, source ← GND).

### Servos — PCA9685 channels 4–13 (SG90s, 5 V rail)

| Channel | Servo | Channel | Servo |
| --- | --- | --- | --- |
| ch4 | Module 1 bottom trapdoor | ch9 | Module 2 pusher |
| ch5 | Module 1 paddle | ch10 | Module 3 bottom trapdoor |
| ch6 | Module 1 pusher | ch11 | Module 3 paddle |
| ch7 | Module 2 bottom trapdoor | ch12 | Module 3 pusher |
| ch8 | Module 2 paddle | ch13 | **Feeder** (360° continuous rotation) |

Signal wires go to the PCA9685 OUT pins (the driver handles the 5 V signal
level from its `V+` rail). Power the servos from the **same external 5 V PSU**
that feeds `V+`.

## Power

1. **Logic:** board powered via USB (the on-board regulator makes 3.3 V for
   the chip and the PCA9685 VCC). 5 V/500 mA from USB is fine — the servos do
   **not** draw from USB.
2. **Servos:** external **5 V PSU (4–10 A)** → PCA9685 `V+`. Never power the
   servos from the board's 5V pin.
3. **Common ground (mandatory):** PSU GND → PCA9685 GND → board GND. Missing
   this is the #1 cause of twitchy servos and random resets.
4. **Bulk capacitance:** 1000–2200 µF across the servo rail is cheap insurance
   against brownouts that corrupt an in-flight routing sequence.
5. **Brownout protection** (ESP32 core): keep the default `Brownout` enabled —
   the firmware's watchdog already aborts cleanly to neutral on a fault.

## Flashing + serial

- **This board has a USB-serial bridge (CH343)** → keep the Arduino IDE
  defaults: **USB CDC On Boot: Disabled** and **Upload Mode: UART0 / Hardware
  CDC**. `Serial` maps to UART0 through the bridge; flashing and Web Serial
  both use that port. (Native-USB-only boards are the exception — see
  `CONTROLLERS.md`.)
- Board: **ESP32S3 Dev Module** · Flash Size: match your module (8/16 MB) ·
  Upload Speed: 921600.
- To force a fresh boot: hold **BOOT**, tap **EN**, release BOOT — then flash.

## Wi-Fi / OTA (this board)

With the Wi-Fi firmware build, this board also joins your LAN (mDNS
`decksift-board.local`, WebSocket port 81) and accepts Arduino IDE updates
over the network. Configure it from the browser: **Calibrate → Wi-Fi & OTA**.
See `SERIAL_PROTOCOL.md` for the commands and `BUILD.md` for the setup walkthrough.

## Quick checklist

- [ ] All IR sensor OUTs land on GPIO 6/7/10/11 (J1 pins 8/9/18/19)
- [ ] PCA9685 SDA/SCL on GPIO 8/9 (J1 pins 14/17), VCC on 3V3, never 5V
- [ ] Servo rail: PCA9685 `V+` ← external 5 V PSU; PSU GND tied to board GND
- [ ] No 5 V logic ever fed into a GPIO
- [ ] No connection on GPIO 0/3/46 (strapping) or GPIO 43/44 (UART bridge)
- [ ] LEDs on PCA9685 ch0–3 via resistors (ch0 = scan light)

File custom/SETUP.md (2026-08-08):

# DeckSift — local runbook (this machine)

How to run the app, connect to it, and do the one-time first-run setup.

## The web interface

| URL | What |
| --- | --- |
| **https://decksift.local:5173** | The app, friendly hostname (HTTPS — required for Web Serial). See below for the one-time setup |
| **http://localhost:5173** | The app fallback (works the same; `localhost` is already a secure context) |
| http://localhost:3001 | The API server (the browser talks to it via the Vite `/api` proxy) |
| 127.0.0.1:5433 | Local PostgreSQL (database `mault`) |

**decksift.local one-time setup** (needs no admin except the hosts line):

```powershell
node scripts/ssl-setup.mjs        # downloads mkcert, issues + trusts a local cert
# then, as admin, add to C:\Windows\System32\drivers\etc\hosts:
#   127.0.0.1  decksift.local
# then restart the web server (start-web.cmd)
```

The app also works from other devices on your LAN via `http://<pc-ip>:5173`
(the API is same-origin through the Vite proxy, so no CORS setup needed).

In-app pages: `/app` scanner · `/app/collections` · `/app/library` (card
browser + set completeness) · `/app/bins` · `/app/calibrate` ·
`/app/settings` (games) · `/app/admin` (card sync) · `/app/monitor`.

## Starting / stopping the stack

```powershell
# Postgres (portable, auto-starts at logon if you ran `install`)
node scripts/local-db.mjs status      # is it running?
node scripts/local-db.mjs start|stop

# API server (detached; output appends to server.log at the repo root)
#   Run the next two lines from the repo root.
powershell Start-Process -FilePath ".\scripts\start-server.cmd" -WindowStyle Hidden

# Web UI (detached)
powershell Start-Process -FilePath ".\scripts\start-web.cmd" -WindowStyle Hidden
```

The API has a health check — `curl http://localhost:3001/api/health` returns
`{"success":true,"status":"ok",...}` (503 when the database is down).

## First-run setup (done once — already executed on this machine)

The database on this machine is already seeded. To re-create or repair the
setup on a fresh install, run the seeder (idempotent, safe to re-run):

```powershell
cd packages\server
npx tsx --env-file ..\..\.env scripts\seed-local.ts
```

This creates:

1. **Games** — the five sync-capable game rows (`mtg`, `yugioh`, `digimon`,
   `gundam`, `pokemon`) with their real data-source URLs and per-game rarity
   field definitions. The **key must match** the server adapter — the seeder
   uses the correct keys.
2. **Collection** — `My Collection` (MTG), active.
3. **Bin set** — `Default 7 Bins`, active, 7 bins with bin 7 as catch-all.
4. **Bundle config** — `Standard Bundle (15/15/5/5)` (MTG rarities).

Then run the card sync for each game you'll actually use:

1. Open **https://decksift.local:5173** (or **http://localhost:5173**).
2. **Admin** → run the **sync** for each game. The first MTG sync downloads the
   Scryfall catalog (~54k unique-artwork cards) and embeds each with the local
   SigLIP model — roughly **9-10 hours** on this machine's GPU, one-time and
   resumable (it skips cards already embedded, and the catalog itself is cached
   on disk so re-runs skip the download). The sync log shows live progress
   (`[N/53952] Card Name (SET)`); it can be cancelled and restarted safely.
3. Back to the scanner, select the collection, connect the sorter + camera,
   and scan.

> Until sync completes for a game, scanning can't match anything — the
> `cards` table is empty and the search has nothing to compare against.

## Bundle mode (fixed-composition bundles, no duplicates)

The **Bundle Mode** panel lives on the scanner page (left sidebar).

- **Create a bundle** — name + rarity targets (rarity, count, bin) + reject
  bin. Example: common ×15 → bin 1, uncommon ×15 → bin 2, rare ×5 → bin 3,
  mythic ×5 → bin 4, reject → bin 7. The default 15/15/5/5 config is pre-seeded.
- **Start a run** — bundle routing switches on. Every scanned card is offered
  to the run: if it's already in the bundle, its rarity slot is full, or its
  rarity isn't part of the recipe, it routes to the **reject bin**. Otherwise it
  routes to its target bin and the count advances.
- **Progress** — the panel shows live per-rarity counts (e.g. 7/15 common) and
  an overall bar; the card grid records every scan as usual.
- **Complete** — when all targets are met the run auto-completes, auto-feed
  pauses, and the bundle is done. Start the next run to assemble another.
- **Resume** — runs persist in Postgres; reloading or restarting the app
  resumes the active run exactly where it left off.
- **Game (SKU prefix)** — pick the game when creating a bundle (defaults to
  the active collection's game). Each run gets an inventory **SKU** at start:
  `{GAME}-{CARD_COUNT}-{SEQ}` (e.g. `MTG-40-001`, `YGO-40-002`). Acronyms:
  MTG, YGO, PKM, DIG, GUN (unknown keys fall back to `TCG`).
- **Bundle inventory** — past runs are listed under the panel with their SKU,
  card count, value, and status. Each run stores the full list of placed
  cards; open it to view the cards, or **download the bundle CSV** — an
  inventory record (SKU, config, game, date, total value + per-card rows) for
  handling sales disputes / “missing card” claims.

Rarity names must match what the sync stores for that game (all lowercased):
MTG uses `common/uncommon/rare/mythic`; Yu-Gi-Oh! uses
`common/rare/super rare/ultra rare/secret rare`; Digimon uses
`common/uncommon/rare/super rare/secret rare`. Edit the rarity strings in the
bundle editor to match the game you're scanning.

### Bundle options

- **Allow duplicates** — when off (default), the same card id can only be
  placed once per bundle run; repeats route to the reject bin. When on, copies
  of the same card all count.
- **Holo detection** — when off (default), the scan light/foil verdict is
  ignored: a holo common and a plain common are both just “common”. When on,
  each rarity target gains a foil filter (**Any / Non-foil / Foil**), so you
  can build e.g. a non-holo common bundle (holo commons go to the reject bin)
  or a foil-chase bundle.

## Bin capacity limits (overflow protection)

The physical bins are 155 mm (module 1, nearest the feeder), 110 mm (module
2), 65 mm (module 3), and 60 mm for the reject/catch-all channel. The app sets
a per-bin max card count so a run can never overflow:

```
maxCapacity = floor((binHeightMm / 0.3 mm average card thickness) × 0.9)
```

| Bins | Height | Max cards |
| --- | --- | --- |
| 1–2 (module 1) | 155 mm | 465 |
| 3–4 (module 2) | 110 mm | 330 |
| 5–6 (module 3) | 65 mm | 195 |
| 7 (reject) | 60 mm | 180 |

When a bin hits its limit the app routes overflow to the catch-all bin and
pauses auto-feed. The 10 % headroom keeps the top of a full stack clear of the
mechanism above. The values live in `BIN_HEIGHTS_MM` / `CARD_THICKNESS_MM` in
the shared package; `cd packages/server && npx tsx scripts/apply-bin-capacities.ts`
re-applies them to the active bin set after a change.

## Sorting by value (e.g. "over $2 → reject bin")

Binning is fully configurable per bin, including numeric price rules:

- The bin field **Price (USD)** (`prices.usd`, with greater-than /
  less-than etc.) is built in; **Price (USD, Foil)** (`prices.usd_foil`) was
  added for foil-value sorting.
- Example: Bin 6 rule `Price (USD) greater than 2` = "valuable" pile;
  Bin 7 (catch-all) = everything else. Or invert it: a low-value reject bin
  under $2, everything else to the good bins. Any combination of rules per
  bin works — rarity, set, type line, name, mana value, price, color.

### Where prices come from

| Game | Prices in the DB? |
| --- | --- |
| MTG (Scryfall) | ✅ bulk data includes `prices.usd` / `usd_foil` |
| Yu-Gi-Oh! (YGOPRODeck) | ✅ `card_prices` → `prices.usd`/`eur` (wired) |
| Gundam / Pokémon / Digimon | ❌ their sources carry no price data — value rules won't fire |

## Set-chase mode (complete a set automatically)

The **Chase** panel sits on the scanner page (left sidebar).

- **Create a chase** — name + game + set code + chase bin + reject bin
  (optionally bind a collection so cards you already own are skipped).
- **Start a run** — every scanned card is offered to the chase: if it's part
  of the set, isn't already found this run, and isn't already owned (when a
  collection is bound) it routes to the chase bin. Off-set, owned, and
  duplicate cards route to the reject bin with a reason toast.
- **Resume** — runs persist in Postgres; reload/restart resumes the active run.
- Priority when several modes are on: **bundle > chase > wishlist > normal
  bin rules**. Bin capacity is still enforced — a full chase bin pauses the
  machine until you empty it.

Set codes are uppercased on the server; enter e.g. `JUSH-EN040` (YGO) or the
set code shown in the library for the game you're scanning.

## Wishlist routing (specific cards to their own bin)

The **Wishlist** panel sits on the scanner page (left sidebar).

- **Create a wishlist** — name + game + bin. Add items as a specific card id
  (from the library) or a name pattern (e.g. `Blue-Eyes`).
- A wishlist only fires when the **active collection's game** matches the
  wishlist's game. A matched card routes to the wishlist bin before normal bin
  rules; capacity is still enforced.
- Name patterns match case-insensitively against the card name.

## Collection tools (scanner page + library)

- **Bundle value** — the bundle panel shows the live $ total of the run
  (from `prices.usd` when the game has prices; see below).
- **Export CSV** — toolbar button on the scanner page downloads
  `collection-<date>.csv` (name, set, rarity, collector #, price, qty, foil,
  bin) for everything scanned this session.
- **TCGplayer CSV** — toolbar button downloads `tcgplayer-<date>.csv`, a
  TCGplayer-compatible inventory file (`name, set_name, condition, quantity,
  purchase_price, list_price, tcgplayer_id`). Condition defaults to **Near
  Mint** (edit before upload if you grade differently); foil scans get
  `(Foil)` in the name so TCGplayer's matcher picks the foil product;
  `list_price` is filled from the card's price when the source has one;
  `tcgplayer_id` is left blank until the API integration lands. Upload it in
  the TCGplayer seller portal → Inventory → Import.
- **Digitize mode** — toggle in the scanner sidebar. When on, every scanned
  card is recorded to the collection but **not sorted**: no bin rules, bundles,
  chase, or wishlist apply, and cards route to the catch-all bin so the
  machine keeps moving. Use it to bulk-record a library (e.g. for later
  pricing or TCGplayer listing) without deciding where anything goes.
- **Orientation tolerance** — the scan crop auto-detects a card fed upside
  down (180°) and rotates it upright before matching, so cards don't need to
  be perfectly aligned end-over-end.
- **Duplicates** — toolbar button lists every card scanned more than once, so
  doubles are easy to spot.
- **Set completeness** — switch on the library page; enter a set code and see
  `owned / total` (and %) for cards scanned this session.

## Known gaps / roadmap (what's not done yet)

- **One Piece / Dragon Ball** — no public API; needs a community dataset via
  `import-cardset.ts` (see `custom/TCGS.md`).
- **Holo detection** — heuristic v1 + two-frame scan light are built;
  thresholds need calibration on the real rig (`custom/PLAN.md` checklist).
- **2 s/card pipeline** — firmware state machine + pipelined feed, deferred
  to machine build (`custom/PLAN.md`).
- **Pricing for Gundam/Pokémon/Digimon** — would need a price source/API.

## Everything is local (after first sync)

Postgres, the API, the web app, the vision model (SigLIP), and card art
(disk-cached) all run on this machine. Only the one-time sync and any brand-new
card art need the internet.

## AI GPU — GTX 970 dedicated embedding card

The vision model runs on a **dedicated GTX 970** (DirectML adapter 1), not the
Quadro M4000 that drives the desktop. Measured 2026-08-08 on this machine
(`pnpm bench:vectorize`, fp32, 15 runs):

| GPU | Full scan-path embed | Model forward |
| --- | --- | --- |
| Quadro M4000 (adapter 0, primary display) | 374 ms mean | 332 ms mean |
| GTX 970 (adapter 1, no display) | **284 ms mean** | **243 ms mean** |

→ ~1.3× faster per scan, and because the 970 is not the primary display, the
embedding load no longer shares the GPU with the desktop compositor — a full-
tilt sync no longer makes Windows feel sluggish (the pacing tunables below
still apply, but as a safety net rather than a necessity).

Config (`.env` / start command):

```
VECTORIZE_DEVICE=dml          # use DirectML (already set in .env)
VECTORIZE_DML_DEVICE_ID=1     # DirectML adapter index; 1 = GTX 970 on this machine
# VECTORIZE_DTYPE=fp16        # optional: ~10% faster on the 970 (258 vs 284 ms),
                              # slightly reduced embedding precision — fp32 is the default
```

**Adapter numbering gotcha:** `VECTORIZE_DML_DEVICE_ID` is the *DirectML* index
(DXGI order — primary display first), not the `nvidia-smi` index. On this
machine `nvidia-smi` lists GTX 970=0 / M4000=1, but DirectML is the reverse
(0=M4000, 1=GTX 970). To verify which GPU is doing the work, watch
`nvidia-smi` during a sync: the 970 should peg while the M4000 stays at
normal desktop load. If the GPU topology changes (different display wiring,
another card), re-check and adjust `VECTORIZE_DML_DEVICE_ID`.

## Multi-language cards

Foreign-language cards scan fine — the vision matcher reads artwork, not
text (verified: a Japanese MTG card matches its English row at distance 0.25
vs the 0.30 threshold). Pokémon rows also carry their localized names
(fr/de/es/it/pt), and the Library search matches them — typing "Dracaufeu"
finds Charizard. MTG/Yu-Gi-Oh! sources don't ship localized names (see
`custom/TCGS.md` "Multi-language cards" for the per-game table). The UI
stays English throughout.

## Machine responsiveness during sync

The sync saturates the GPU while it runs (that's the embedding step), and on
Windows the desktop compositor shares the GPU — so a full-tilt sync can make
Windows feel sluggish even though CPU is nearly idle. The server now paces
itself: it runs near-full speed when idle and backs off when a scan is in
progress (last 5 s). Tunables (in `.env` or the start command):

```
SYNC_FETCH_BATCH=16      # parallel image fetches
SYNC_EMBED_BATCH=8       # GPU embedding batch (8 is proven stable on this GPU)
SYNC_PACE_SCAN_MS=200    # delay per batch while scanning
SYNC_PACE_IDLE_MS=10     # delay per batch when idle
```

Postgres also starts with `shared_buffers=1GB` (was the 128 MB default) so the
card catalog + vector index stay in RAM. Restart Postgres after a change
(`node scripts/local-db.mjs stop && start`).

Nothing here needs caching *in* the GPU: the lookup step (vector search) runs
in Postgres on CPU, and the SigLIP model is already loaded into VRAM once and
reused for every scan/sync embed.

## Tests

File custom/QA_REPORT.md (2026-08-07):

# QA Report — DeckSift commercial-readiness review

**Date:** 2026-08-08 · **Reviewer:** QA agent · **Scope:** all uncommitted work in the working tree (Items 63–64, test suite, retry/logger wiring, CI tests job, `RESEARCH_MARKET.md`). Firmware deliberately not reviewed.

---

## 1. Verdict summary

**APPROVE — with minor hardening follow-ups before commercial deployment.**

- All four verification commands pass from `C:\Mault Revised\mault`: `pnpm test` (11 files / 94 tests green), `pnpm typecheck` (fresh, cache-bypassed), `pnpm lint` (fresh), `pnpm build` (server forced; web cached-hit then re-verified).
- Runtime smoke tests pass: `/api/health` → 200, and `/api/admin/sync/sources` → 200 with all **11** sync sources.
- **No Critical or High findings.** The implementation agent's work is correct, well-scoped, and the tests are genuinely meaningful (verified against the source they cover).
- Two **Medium** hardening edges in the new `fetchWithRetry` wiring (abort budget vs. backoff sleeps; retry added to calls that have no timeout at all). Both are edge cases, not current-path bugs.
- **Verification caveat:** the API currently running on 3001 predates the server changes (process uptime ~18.7 h; `server.log` contains zero JSON log lines). The smoke test validates the environment and routes, but the new retry/logger code is *not* live on that process — it is covered instead by the unit tests, forced typecheck, and forced server build. The API should be restarted once to load the new code (I did not restart it, per instructions).

---

## 2. Verification matrix

All commands run from `C:\Mault Revised\mault` (Node v22.23.2, pnpm 9.1.3 — matches CI).

| Command | Result | Notes |
| --- | --- | --- |
| `pnpm test` | ✅ PASS — 11 files, 94/94 tests, 808 ms | vitest 4.1.10; shared + server suites |
| `pnpm typecheck` | ✅ PASS (3/3 packages) | First run was a turbo cache-hit; re-ran `pnpm exec turbo typecheck --force` — cache-miss, all three packages (incl. new `*.test.ts` files) typecheck clean |
| `pnpm lint` | ✅ PASS | web-only (server/shared define no lint script); re-ran `pnpm exec turbo lint --force` |
| `pnpm build` | ✅ PASS (server + web) | Server re-built forced (`turbo build --filter=@magic-vault/server --force`); bundle verified to contain the new code (`Health check failed`, `retry-after`, `DATABASE_URL` strings present in `dist/index.js`) |
| `pnpm install --frozen-lockfile` | ✅ PASS | Lockfile consistent — the CI `tests` job's install step will not fail |
| `curl http://localhost:3001/api/health` | ✅ `{"success":true,"status":"ok",...}` HTTP 200 | uptime 67318 s |
| `curl http://localhost:3001/api/admin/sync/sources` | ✅ HTTP 200, 11 sources | mtg, gundam, pokemon, yugioh, digimon, lorcana, onepiece, starwars, unionarena, fab, pokemonpocket |
| Editor diagnostics | ✅ No errors/warnings on any changed TS file | Only pre-existing warnings in `web/src/app/routes/landing/hero.tsx`, `web/src/index.css`; firmware errors ignored (out of scope) |

---

## 3. Findings by severity

### Critical
None.

### High
None.

### Medium

**M1 — Caller's abort budget does not cover inter-attempt backoff sleeps**
`packages/server/src/lib/retry.ts:57-58, 66` (with docstring claim at lines 7–9)

The header comment says "The caller still owns the overall budget: pass a pre-created `signal`… an AbortError aborts the whole call." That is only true for the `fetch` calls themselves — the `sleep()` between attempts is a plain `setTimeout` that is **not** abort-aware. In `art-cache.ts:73`, `fetchWithRetry(url, { signal: AbortSignal.timeout(30_000) })` can therefore stall well beyond 30 s: e.g. a 429 with `Retry-After: 60` → `retryAfterDelayMs` returns 60 000 ms → `sleep(60s)`; the timeout fires at 30 s but nothing is awaiting the signal; the next fetch attempt then rejects with an AbortError. Result: a 60 s+ stall on the image-proxy path where the caller expected a hard 30 s cap, and the failure surfaces as an AbortError instead of the intended error type.

Suggested fix: make the sleep abortable (e.g. `AbortSignal.any([init.signal, AbortSignal.timeout(...)])` into an abortable sleep), or cap `retryAfterDelayMs` at a sane maximum (e.g. `Math.min(seconds, 30) * 1000`), and fix the docstring.

**M2 — Retry added to external calls that have no timeout at all**
`packages/server/src/lib/scryfall/search.ts:26, 57`; `packages/server/src/lib/card-search/generic.ts:189, 196, 209, 237`

The art-cache call site got a 30 s `AbortSignal.timeout`; the Scryfall and generic-adapter sites did not (they were bare `fetch` before, and remain bare now — no regression in that respect). But the new retry semantics multiply the stall: a hung upstream (undici has no whole-request default timeout) previously stalled once; it now stalls 3× plus backoff before failing. For a "live shop counter" deployment this is the wrong tradeoff on the search path.

Suggested fix: pass `signal: AbortSignal.timeout(...)` (e.g. 10–15 s for search, longer for bulk) at these call sites, or add a default timeout inside `fetchWithRetry` when `init.signal` is absent.

### Low

**L1 — `JSON.stringify` can throw on circular `details`, masking the original error**
`packages/server/src/lib/logger.ts:23`

`write()` calls `JSON.stringify(entry)` unguarded. All current call sites pass `Error` instances or strings (serialized by `serialize`), so this is latent — but the logger is invoked from `app.onError`, `uncaughtException`, and `unhandledRejection`. If any future call site logs a circular object (a request/context object is the classic case), the stringify throw replaces the original error: the log line is lost and, inside the error handlers, the new exception propagates (in `unhandledRejection` it re-enters `uncaughtException` → second throw → crash without the intended exit path).

Suggested fix: wrap `JSON.stringify` in try/catch and fall back to `String(details)` / a `<unserializable>` marker.

**L2 — Mixed log formats: two `lib/` files still use `console.error`**
`packages/server/src/lib/art-cache.ts:49`; `packages/server/src/lib/sync-cache.ts:54`

`index.ts` now emits one JSON line per event, but `saveArtToCache` and `saveCachedCatalog` still write multi-line `console.error` stacks. The same process therefore interleaves JSON and non-JSON lines in `server.log`, undercutting Item 64's stated goal ("server.log is greppable/tailable by ops tooling"). Pre-existing code, but `art-cache.ts` was touched by this change anyway.

Suggested fix: migrate both to `logger.error` (the failure paths already receive an `err`).

### Nit

**N1 — Capacity tests recompute the implementation formula**
`packages/shared/src/constants/sort-bins.constant.test.ts:13-25`

`expect(computeBinCapacity(1)).toBe(Math.floor((155 / CARD_THICKNESS_MM) * 0.9))` mirrors the implementation, so a change to `CARD_THICKNESS_MM` (0.3 → 0.35) or `BIN_HEADROOM_FACTOR` would pass unnoticed; only the hardcoded heights are pinned. Suggest asserting known-good literals (bin 1 = 465, bin 7 = 180) alongside the existing property test ("never exceeds headroom"), which is the strongest test in the file.

**N2 — retry tests don't pin backoff timing and miss two branches**
`packages/server/src/lib/retry.test.ts`

Attempt counts are asserted, but no test verifies the sleep durations (a regression that always slept 0 ms would still pass given `advanceTimersByTimeAsync(10_000)`); no test for `retries: 1` (single attempt, no retry); no test for a non-numeric `Retry-After` (HTTP-date) falling back to backoff. The "never retries caller-initiated aborts" test is meaningful for the retry loop, but the mock rejects with a hand-built AbortError, so it would not catch a broken *signal-based* abort path.

**N3 — `vitest` devDependency duplicated at root + shared + server**
`package.json`, `packages/shared/package.json`, `packages/server/package.json`

Only the root copy is used (tests run from root via `vitest run`). Harmless and arguably good for package self-containment (each package's `tsc --noEmit` resolves `vitest` types without relying on hoisting), but worth a one-line comment in the config if intentional, since the current `vitest.config.ts` comment implies root-only ("single test runner for the whole monorepo").

---

## 4. Test-quality assessment

**Overall: good.** I read every test file against the source it covers. The suite is meaningful — spot checks below; I also mentally "mutation-tested" the main behaviors (would the test fail if the code broke?).

- **`evaluate-bin.test.ts` (22 tests) — strong.** Would catch: broken array-equality, missing numeric coercion (string "12.50" → 12.50), wrong catch-all fallback, first-match-wins ordering, empty-group handling, `contains_any/all/none` logic, and nested-group evaluation. The `card()`/`bin()`/`condition()` helpers make each case read as a spec. No vacuous assertions found.
- **`retry.test.ts` (8 tests) — strong on the retry/no-retry decision.** Would catch: retrying 404s, retrying aborts, not retrying 500s, ignoring `Retry-After`, giving up too early/late. Gaps are N2 above (timing not asserted, two branches untested).
- **`card-search/cache.test.ts` (6 tests) — strong.** Would catch: no caching, no in-flight dedupe, caching failures, never expiring, and query normalization ("  Sol Ring " ≡ "sol ring") — the last is a nice behavior-level assertion, not just a mock-count check.
- **`scryfall/search.test.ts` (7 tests) — strong.** Would catch: URL-encoding, missing `unique=prints`, 404 → friendly message, 5xx retried 3× (asserts `fetchMock` call count under fake timers), query-min-length short-circuit. `SearchById` 404 message asserts both status and id.
- **`art-cache.test.ts` (7 tests) — good.** Disk round-trip, cross-URL isolation, in-flight dedupe, and both failure modes (500 after retries; non-image content-type). Correctly hoists `ART_CACHE_DIR` *before* the module import and cleans up in `afterAll` — the right pattern.
- **`generic.test.ts` (16 tests) — good.** Coercion helpers, proxy URL building, `baseCard` defaults, adapter URL-encoding, result cap at 30, empty-list handling, `searchFilter`, bulk-catalog fallback for `searchById`, sync-source mapping and failure throw.
- **`sync-cache.test.ts` (4 tests) — small but meaningful.** Version-mismatch = miss, missing-game = miss, and the "does not throw on unwritable" test verifies the best-effort contract.
- **`sort-bins.constant.test.ts` (10 tests) — OK, with the N1 tautology caveat.** The color-bin layout tests (5 colors + colorless + catch-all, stable rule ids) are genuinely useful.
- **`scryfall.test.ts` / `scryfall.constant.test.ts` / `game-acronyms.constant.test.ts` (14 tests) — fine.** Boundary values (misprint band edges, confidence clamping at 0/100, `null` handling) are asserted explicitly.

**Verdict on rigor:** the suite would fail if the core logic were broken; I found no test that asserts the wrong thing, and no vacuous test (the closest is N1's formula mirroring, which still pins the physical heights). The 94-test / ~1 s claims in Item 64 are accurate (measured 808 ms).

---

## 5. Regressions or risks

1. **Running API is on pre-change code (verification gap, not a defect).** `uptime: 67318` (~18.7 h) plus zero JSON lines in `server.log` (the last startup line is old-format `[server] Running on port:3001`) show the process on 3001 started before the logger/retry changes. Smoke tests therefore prove the DB/routes/environment, not the new server code. **Action:** restart the API once after merge (e.g. `scripts/start-server.cmd`) and confirm a JSON startup line appears in `server.log`.
2. **No behavioral regression for correct inputs.** Retries only fire on 408/429/5xx or network errors; 4xx and aborts pass straight through — identical observable behavior when upstreams behave. The logger writes to stdout, which `start-server.cmd` already redirects.
3. **Web downscale (Item 63, accepted work) — re-verified, no issues.** `downscaleCanvas` is a no-op for canvases ≤512 px (no upscaling), falls back to the original canvas if `getContext` fails, and only the upload blob is downscaled — foil detection still runs on the full-res frame. Known consequence (documented in Item 63): the persisted debug/capture image is now ≤512 px.
4. **CI parity.** The `tests` job mirrors the existing jobs' setup (pnpm 9.1.3, Node 22, frozen lockfile) and `pnpm install --frozen-lockfile` passes locally, so the new job should not surprise. Note the `vitest.config.ts` include list covers only `shared` + `server` — future web tests would silently not run unless the include list is extended.
5. **Test files are typechecked** as part of each package's `tsc --noEmit` (verified via forced cache-miss typecheck), and `dist/` is turbo-cached — the `.github` job order (`typecheck` then `test`) is fine.

---

## 6. Sign-off recommendation

**Sign-off: APPROVE the working tree** (Items 63–64 + tests + CI + research doc) **for merge, with the following before a shop deployment:**

1. Address M1 (abort-aware backoff sleep or Retry-After cap) and M2 (timeouts on the retried external calls) — the only two production-hardening gaps.
2. Restart the API to load the new server code and confirm JSON logging in `server.log`.
3. Optional polish: L1 (guard `JSON.stringify`), L2 (migrate two `console.error`s), N1–N3.

No code changes were made by QA (findings M1/M2 are design decisions for the implementation agent/lead; everything else is report-only). `RESEARCH_MARKET.md` is coherent, appropriately hedged, and consistent with the repo (its "11-game single machine" claim cross-checks against the 11 sources returned by the live API) — no misleading statements found. Changelog Items 63–64 follow the repo's template (Status / Why / What changed / Behavior notes / How to revert) and their quantitative claims (94 tests, 22 evaluate-bin tests, ~1 s runtime) are accurate.

---

## 7. Re-verification (post-fix)

**Date:** 2026-08-08 (second pass) · **Scope:** Item 65 (M1, M2, L1, L2, N1, N2, N3). Report-only — no files modified, running server untouched.

### Verdict: **APPROVE — all findings genuinely resolved, no regressions found.**

### Fix-by-fix verification

| Finding | Resolved? | Evidence (file:line) |
| --- | --- | --- |
| **M1** abort budget vs. backoff sleeps | ✅ | `retry.ts:52-66` — new `abortableSleep()` races the signal: fires → clears the timer and rejects with `signal.reason`. Both backoff sites (`retry.ts:110, 118`) pass the signal. `retry.ts:37, 77-82` — `Retry-After` capped at 30 s (`MAX_RETRY_AFTER_MS`), unparsable/HTTP-date values fall back to backoff. Docstring (`retry.ts:7-16`) now describes the real semantics and matches the implementation. Dedicated test: `retry.test.ts:152-167` (abort-during-backoff). |
| **M2** no timeout on retried external calls | ✅ | `retry.ts:101` — `init.signal ?? AbortSignal.timeout(timeoutMs ?? 15_000)` created once per call, so every no-signal call site is bounded (15 s default) and retries stay inside the budget. `generic.ts:186, 202, 243` — bulk paths (sync + no-id-endpoint `searchById`) pass `timeoutMs: BULK_FETCH_TIMEOUT_MS` (120 s); search-style calls keep the default. Tests: `retry.test.ts:169-184` (internal timeout, TimeoutError, no retry), `retry.test.ts:186-211` (caller signal owns the budget; internal timeout never overrides). |
| **L1** unguarded `JSON.stringify` | ✅ | `logger.ts:21-32` — stringify wrapped in try/catch; on failure logs `level`/`ts`/`msg` with a `(details omitted: unserializable)` marker instead of masking the original error. |
| **L2** mixed `console.error` in cache files | ✅ | `art-cache.ts:50` and `sync-cache.ts:55` now call `logger.error`. Shell grep confirms **0** `console.error` occurrences in `art-cache.ts` / `sync-cache.ts` (and no `console.` anywhere in `retry.ts`/`logger.ts`). `server.log` will now be uniformly JSON from the server process. |
| **N1** tautological capacity assertions | ✅ | `sort-bins.constant.test.ts:13-29` — known-good literals: unsleeved 465/465/330/330/195/195/180; sleeved 199/77 (verified by hand: `floor(155/0.3×0.9)=465`, `floor(60/0.3×0.9)=180`, `floor(155/0.7×0.9)=199`, `floor(60/0.7×0.9)=77`). Headroom property test retained at `:36-40`. |
| **N2** retry test gaps | ✅ | `retry.test.ts` 8 → 14 tests: `retries: 1` (`:111-116`), HTTP-date `Retry-After` → backoff (`:118-134`), pinned backoff duration — a 0 ms-sleep regression fails (`:136-150`), abort-during-backoff (`:152-167`), internal-timeout bound (`:169-184`), caller-signal-owns-budget (`:186-211`). |
| **N3** vitest devDep duplication undocumented | ✅ | `vitest.config.ts:10-13` — comment explains per-package copies exist for `tsc --noEmit` type resolution, not for running tests. |

### Verification matrix (second pass)

All commands from `C:\Mault Revised\mault`, turbo cache-bypassed where available (Node v22.23.2, pnpm 9.1.3).

| Command | Result |
| --- | --- |
| `pnpm test` | ✅ PASS — 11 files, **100/100** tests (94 prior + 6 new retry tests; matches Item 65's claim), 1.12 s |
| `pnpm exec turbo typecheck --force` | ✅ PASS — 3/3 packages (cache-bypassed) |
| `pnpm exec turbo lint --force` | ✅ PASS — web (cache-bypassed) |
| `pnpm exec turbo build --force` | ✅ PASS — server (tsup) + web (vite), cache-bypassed |
| `pnpm install --frozen-lockfile` | ✅ PASS — lockfile consistent (CI `tests` job safe) |
| Bundle spot-check | ✅ `dist/index.js` contains the new retry symbols (`TimeoutError`, `abortableSleep`-equivalent, `MAX_RETRY_AFTER`) |

### Residual findings

None of the seven findings remain open. Remaining observations (all Nit-level, non-blocking):

1. **Nit — Retry-After cap vs. no-signal budget interplay:** on calls using the internal 15 s timeout, a capped 30 s `Retry-After` can never be fully honored — the 15 s budget fires first (by design: "retried within that budget"). Harmless and documented, but a reader may find `MAX_RETRY_AFTER_MS = 30_000 > timeoutMs` slightly confusing; a one-line comment noting the budget wins would polish it.
2. **Nit — docstring wording:** `retry.ts:15` says the internal timeout is "applied to the fetch"; it is created once per call and bounds fetches *and* sleeps. The next sentence ("still retried within that budget") clarifies, but the first clause is slightly imprecise.
3. **Nit — new `retry.test.ts` internal-timeout/caller-signal tests use real timers** (`vi.useRealTimers()` at `:170, 187`) while the rest use fake timers — a stylistic split, but justified (the internal `AbortSignal.timeout` can't be driven by fake timers; no flakiness observed in 3 runs).
4. **Carried over from §5 (unchanged):** the API running on 3001 still predates Items 64–65 — restart once after merge and confirm a JSON startup line in `server.log`. Item 65's own Behavior notes already flag this.

### Sign-off

**APPROVE.** Item 65 resolves M1, M2, L1, L2, N1, N2, N3 as implemented — each fix was verified in source and, where applicable, pinned by a new test that demonstrably fails if the fix regresses (backoff pin, abort-during-sleep, internal-timeout bound, caller-signal precedence). No regressions found in the full suite, typecheck, lint, or build. The changelog entry follows the repo template and its claims (6 new tests, 100 total) check out exactly.

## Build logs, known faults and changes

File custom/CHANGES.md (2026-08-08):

# Changes from upstream (dishwasher-detergent/mault)

Every entry documents a deliberate change we made for our build: what it is,
why, exactly which code changed, and how to revert it. Entries are cumulative —
later ones may build on earlier ones, so revert in **reverse order** if you need
to roll back multiple items.

**Deployment note:** some changes are a matched pair of firmware + web app edits
and must be updated together — each entry says so explicitly.

---

## Item 1 — Command id / ACK correlation (firmware + web app)

**Status:** implemented, uncommitted.

### Why

The web app's serial layer matched responses by *line order*: after sending
`{"bin":N}` it took the very next line from the Arduino as the response. That
only works because the firmware is fully synchronous today (one command at a
time, `loop()` blocked during routing). It breaks the moment the firmware emits
asynchronous messages — a module-1 jam alert, or a `{"status":"ready"}` after a
brownout reset — which get misread as the reply to the current command. It also
would have broken under the planned non-blocking state machine (custom/PLAN.md),
which will emit async status events mid-route.

### What changed

**Firmware — `arduino/main/main.ino`**
- Commands may now carry an optional numeric `"id"` field; it is extracted at
  the top of `handleCommand()` into `g_cmdId` / `g_hasCmdId`.
- Two new reply helpers, `replyJson(JsonDocument&)` and `replyLiteral(const char*)`,
  echo the id on every response. All command response sites now go through one
  of the two helpers.
- Messages that are not replies to a command — the boot `{"status":"ready"}`
  line and the async `{"error":"jam",...}` alert in `checkModule1Jam()` — stay
  id-less on purpose.

**Web app — `packages/web/src/features/scanner/api/use-serial.tsx`**
- New `waitForId(id, timeout)`: a waiter that only resolves on a parsed message
  whose `id` matches; every other line is ignored (and still dispatched to
  message listeners).
- `sendBin()` now sends `{"bin":N,"id":K}` and awaits `waitForId(K, 15000)`.
- `sendTest()` now sends `{"test":true,"id":K}` and awaits `waitForId(K, 10000)`.
- Line dispatch in `startReading()` now fans out to every waiter whose predicate
  matches, instead of a single FIFO consumer.
- `receiveResponse()` is untouched — it keeps the legacy "next line" semantics
  that the calibration tooling (`use-calibration-page.ts`, `use-module-configs.tsx`,
  `use-feeder-config.tsx`) relies on. A follow-up can migrate those to ids.

**Docs**
- `arduino/main/SERIAL_PROTOCOL.md` — new "Command ids" section.

### Behavior notes / pairing requirement

- **New firmware + new app:** correlated responses — correct behavior.
- **Old firmware + new app:** `sendBin`/`sendTest` will time out because old
  firmware doesn't echo ids. **Flash the firmware and run the new app together.**
- **New firmware + old app:** backward compatible — ids are only echoed when a
  command carries one, and the old app ignores the extra field.

### How to revert

If this change is **not yet committed** (current state):

```bash
git restore arduino/main/main.ino
git restore packages/web/src/features/scanner/api/use-serial.tsx
```

If it **has been committed** as its own commit (recommended when you commit):

```bash
git revert <commit-hash>
```

Then re-upload `arduino/main/main.ino` to the Arduino (Arduino IDE → Upload) and
redeploy/restart the web app to undo the behavior.

---

## Item 2 — Repo tooling: typecheck, firmware compile, CI checks

**Status:** implemented, uncommitted.

### Why

We need a way to validate changes to both halves of the project: typecheck the
web app and compile-check the firmware — locally and automatically in CI.

### What changed

**Scripts / config**
- `packages/web/package.json` — added `"typecheck": "tsc -b"`.
- `package.json` (root) — added `"typecheck": "turbo typecheck"`.
- `turbo.json` — added the `typecheck` task.
- `scripts/arduino-compile.sh` — compiles `arduino/main` for the Uno R4 Minima
  with arduino-cli (installs the `arduino:renesas_uno` core plus ArduinoJson and
  the Adafruit PWM Servo Driver library on first run).
- `.github/workflows/checks.yml` — CI job running `pnpm typecheck` + `pnpm lint`
  (web) and `arduino-cli compile` (firmware) on pushes to master/custom and on
  pull requests. Requires Actions enabled on the fork (same setting as the
  sync-upstream workflow).

**Local tooling (this machine, per-user, no admin)**
- Node.js 22.23.2 + npm (portable zip) at `C:\Users\nsiro\.local\node`
- pnpm 9.1.3 via corepack (matches the repo's `packageManager` pin)
- arduino-cli 1.5.2 at `C:\Users\nsiro\.local\arduino-cli`
- Both `~/.local/node` and `~/.local/arduino-cli` added to the user PATH

### How to revert

Uncommitted:

```bash
git restore package.json
git restore packages/web/package.json

git restore turbo.json

git restore scripts/arduino-compile.sh

git restore .github/workflows/checks.yml
```

For the local tool installs: delete `C:\Users\nsiro\.local\node` and
`C:\Users\nsiro\.local\arduino-cli`, and remove the two entries from the user
PATH (Settings → Environment Variables, or `setx`).

---

## Item 3 — Single image encode + server-hydrated card search

**Status:** implemented, uncommitted.

### Why

Two per-scan inefficiencies: (1) the same card frame was JPEG-encoded twice
(once for the debug image via `toDataURL`, once for the upload via
`canvasToBlob`); (2) after the image search returned distance-only matches,
the client fired one **external** card-API request per close match
(`getCardById` → Scryfall/Gundam/Pokemon) to resolve card details.

### What changed

**`packages/shared`**
- `SearchCardMatch` gained an optional `card` field (`PlayingCard | null`).
- `CLOSE_MATCH_DELTA` (0.05) moved to shared constants so the server and
  client filter on the same value.

**Server**
- `lib/card-cache.ts` (new) — `resolveCardDetails()`: fetches card details
  via the game adapter with an in-memory 1-hour/500-entry cache, so scanning
  a playset fetches each card from the external API once instead of once per
  scan.
- `routes/card.ts` (POST `/api/cards`) — resolves the game adapter once,
  hydrates the close matches with full card data, and returns them in the
  single search response. `lib/card-search/resolve.ts` now also returns
  `gameKey` from `resolveCardSearch`.

**Web app**
- `use-card-scanner.ts` — `searchCardImage()` encodes once (`canvasToBlob`)
  and derives the debug data URL from the same blob via a new `blobToDataUrl`
  helper; it now reads hydrated `card` data straight from the search response
  instead of looping `getCardById`. The old client-side `CLOSE_MATCH_DELTA`
  constant was removed (server filters now).

### Behavior notes

- Response contract for POST `/api/cards` is unchanged in shape (`data` is
  still `SearchCardMatch[] | null`); close matches now carry `card`.
- If an external hydration fails, the match is returned with `card: null` and
  the client skips it (same net effect as the old per-match fetch failing).
- No DB schema change; no migration needed.

### How to revert

Uncommitted:

```bash
git restore packages/shared/src/interfaces/api.interface.ts

git restore packages/shared/src/constants/scryfall.constant.ts

git restore packages/server/src/lib/card-cache.ts

git restore packages/server/src/lib/card-search/resolve.ts

git restore packages/server/src/routes/card.ts

git restore packages/web/src/features/scanner/api/use-card-scanner.ts
```

---

## Item 4 — EEPROM calibration persistence + protocol version handshake

**Status:** implemented, uncommitted.

### Why

Calibration lived only in firmware RAM, so the app re-pushed it on every
connect — and a mid-session reboot (power blip) silently reverted the machine
to stock pulses, misrouting cards until the operator noticed. There was also
no way for the app to detect that it was talking to incompatible firmware.

### What changed

**Firmware — `arduino/main/main.ino`**
- `EEPROM` persistence: a versioned `PersistedCalibration` block (magic +
  version guard) is loaded in `setup()` before any servo moves and saved on
  every `setConfig`/`setFeederConfig`.
- New commands: `{"saveConfig": true}` and `{"resetConfig": true}`.
- Boot message now reports the protocol version:
  `{"status":"ready","proto":2}`.

**Web app**
- `features/scanner/constants.ts` — `EXPECTED_PROTO_VERSION = 2`.
- `use-serial.tsx` — the connect flow parses the boot message and shows a
  warning toast when the firmware's `proto` doesn't match the app's.

**Docs**
- `arduino/main/SERIAL_PROTOCOL.md` — boot message, `saveConfig`/
  `resetConfig` commands, EEPROM persistence notes.

### Behavior notes

- Stale stored config (older layout, changed hardware) is detected by the
  magic/version guard and ignored — factory defaults are used instead.
- EEPROM writes happen on connect (config push) and calibration saves, not on
  individual servo tweaks — flash endurance is a non-issue.

### How to revert

Uncommitted:

```bash
git restore arduino/main/main.ino

git restore packages/web/src/features/scanner/constants.ts

git restore packages/web/src/features/scanner/api/use-serial.tsx
```

Re-upload the firmware and restart the app. Note: firmware and app are a
matched pair — the `proto` handshake only exists on the new firmware.

---

## Item 5 — Full command-id correlation + single feed path

**Status:** implemented, uncommitted.

### Why

Item 1 only correlated `sendBin`/`sendTest`. The feeder, auto-feed, and
calibration commands still used legacy "next line wins" matching — the exact
race we fixed for bin commands — and the feed logic was duplicated in two
places (`card-scanner.tsx` and `use-scanned-cards.tsx`) with already-drifted
error handling. This mattered more once the jam system started emitting async
messages from all three modules (Item 6).

### What changed

**`use-serial.tsx`**
- New `sendCommandWithResponse(data, timeout)` — attaches a command id, sends,
  and waits for the id-matched reply (same mechanism as `sendBin`).
- New `sendFeed()` — id-correlated `{"feeder":true}` with a 10 s timeout.

**Callers migrated to id-correlated responses**
- `use-scanned-cards.tsx` `triggerAutoFeed` → `sendFeed()` (consolidated).
- `card-scanner.tsx` `handleFeed` → `sendFeed()`; `handleClearDevice` →
  `sendCommandWithResponse`.
- `use-module-configs.tsx` + `use-feeder-config.tsx` pre-test config pushes and
  save handlers → `sendCommandWithResponse`.
- `use-calibration-page.ts` `readIR` → `sendCommandWithResponse` (no more
  manual `JSON.parse`).
- `receiveResponse` is no longer used by any of the migrated paths (kept in the
  API for compat).

### How to revert

```bash
git restore packages/web/src/features/scanner/api/use-serial.tsx

git restore packages/web/src/features/scanner/api/use-scanned-cards.tsx

git restore packages/web/src/features/scanner/components/card-scanner.tsx

git restore packages/web/src/features/calibration/api/use-module-configs.tsx

git restore packages/web/src/features/calibration/api/use-feeder-config.tsx

git restore packages/web/src/features/calibration/api/use-calibration-page.ts

git restore packages/web/src/features/scanner/types.ts
```

---

## Item 6 — Jam detection on all modules + boot recovery report

**Status:** implemented, uncommitted.

### Why

The jam watch only covered module 1 and only while idle — a card stuck at
module 2 or 3 was silent, and a power-loss reboot left cards sitting in the
mechanism with nobody told.

### What changed

**Firmware — `arduino/main/main.ino`**
- `checkModule1Jam()` → `checkModuleJams()`: per-module timers watch all three
  module IR sensors while idle; each reports `{"error":"jam","module":N}`
  once after `JAM_TIMEOUT_MS` (renamed from `MODULE1_JAM_TIMEOUT_MS`, still
  20 s).
- On boot, any module IR already blocked emits `{"error":"recovered",
  "module":N}` after `ready` so the operator knows to clear the device.

**Web app — `card-scanner.tsx`**
- `useSerialMessage` now surfaces `recovered` messages as a warning toast with
  a clear-device hint. Jam messages from modules 2/3 already paused the scanner
  via the generic path.

### How to revert

```bash
git restore arduino/main/main.ino

git restore packages/web/src/features/scanner/components/card-scanner.tsx
```

Re-upload the firmware.

---

## Item 7 — Per-bin capacity (software bin-full detection)

**Status:** implemented, uncommitted. **Requires a DB change — see below.**

### Why

No bin-full sensors exist, so the machine would happily feed into a full bin.
A software count per bin pauses routing when a bin reaches its configured max.

### What changed

- **DB:** `bins.max_capacity` integer, default 0 (= unlimited) — added to
  `packages/server/src/db/schema.ts`.
- **Shared:** `BinConfig.maxCapacity` + `DefaultBinInit.maxCapacity`.
- **Server `bins.ts`:** `maxCapacity` carried through create, copy, update, and
  read paths.
- **Web:** capacity input in the bin config panel; `use-scanned-cards.tsx`
  counts cards per bin per session (`binCountsRef`), refuses to route into a
  bin at capacity, pauses auto-feed, and shows a "Bin N is full — empty it and
  re-enable auto-feed" toast. Counts reset when auto-feed is re-enabled, the
  collection changes, or the card list is cleared. The catch-all bin is
  subject to the same check.

### Applying the DB change

This repo's migration history is **out of sync with `schema.ts`** (upstream
predates it: the last snapshot still models the old `user_id` RLS schema, so
`drizzle-kit generate` produces a large wrong diff). This project therefore
runs on the `db:push` workflow — apply the column against the live database:

```bash
pnpm --filter @magic-vault/server db:push
```

or manually: `ALTER TABLE bins ADD COLUMN max_capacity integer NOT NULL DEFAULT 0;`

Until this is applied, the API will error on bin queries/updates referencing
`max_capacity`.

### How to revert

```bash
git restore packages/server/src/db/schema.ts

git restore packages/server/src/routes/bins.ts

git restore packages/shared/src/interfaces/sort-bins.interface.ts

git restore packages/shared/src/constants/sort-bins.constant.ts

git restore packages/web/src/features/bins/api/sort-bins.ts

git restore packages/web/src/features/bins/api/use-bin-configs.tsx

git restore packages/web/src/features/bins/types.ts

git restore packages/web/src/schemas/sort-bins.schema.ts

git restore packages/web/src/features/bins/components/bin-config-panel.tsx

git restore packages/web/src/features/scanner/api/use-scanned-cards.tsx
```

(`max_capacity` in the DB can stay or be dropped — harmless if left.)

---

## Item 8 — Captured-image dedupe + prune script

**Status:** implemented, uncommitted.

### Why

Every scanned card stored a full base64 JPEG in
`collection_cards.captured_image_data_url` (~200–500 KB each), even for
repeated cards in a session — DB bloat you feel in backups and queries.

### What changed

- **App (`use-scanned-cards.tsx`):** the first capture of each unique card id
  in a session is remembered and reused for duplicates (per-card image dedupe
  instead of a fresh JPEG per copy). Reset on collection change / clear.
- **Server:** new maintenance script `packages/server/src/lib/prune-images.ts`
  + `pnpm --filter @magic-vault/server db:prune-images` — nulls
  `captured_image_data_url` for scans older than 30 days.

### How to revert

```bash
git restore packages/web/src/features/scanner/api/use-scanned-cards.tsx

git restore packages/server/src/lib/prune-images.ts

git restore packages/server/package.json
```

---

## Item 9 — Diagnosis fixes

**Status:** implemented, uncommitted.

### What changed

- **`use-serial.tsx` / `scanner/types.ts`:** removed the dead `receiveResponse`
  public API (zero consumers remain after Item 5 migrated everything to
  id-correlated responses).
- **Firmware (`main.ino`):** replaced the persistent `String inputBuffer` with
  a fixed `char` buffer (`handleCommand` now takes `const char*`) — removes
  the heap-fragmentation risk on all-day sessions.
- Root `eslint .` across all packages: clean.

### How to revert

```bash
git restore packages/web/src/features/scanner/api/use-serial.tsx

git restore packages/web/src/features/scanner/types.ts

git restore arduino/main/main.ino
```

---

## Item 10 — Stage-1 watchdog / interruptible timing

**Status:** implemented, uncommitted.

### Why

The firmware only ran its jam watch *between* commands, because `delay()`
blocked `loop()` — a jam during an operation wasn't seen until the operation
finished, and a stuck sequence ran unbounded. The app also had no way to tell
if the board was hung short of a 15 s bin timeout.

### What changed

**Firmware — `arduino/main/main.ino`**
- `interruptibleDelay(ms)` — replaces `delay()` inside command handlers: polls
  the jam sensors and the command watchdog while waiting, returns `false` when
the command should abort.
- `jamAbortRequested` — set when a new jam alert fires; cleared at the start
  of every command; checked by `waitForCard`, `runFeeder`, and
  `interruptibleDelay`.
- `commandGuardStart(budgetMs)` / `commandDeadline` — per-command watchdog
  budgets: routeCard 15 s, test 10 s, clearDevice 5 s.
- `runFeeder`/`settleAndStopFeeder` are abort-aware (`FEED_ABORTED` result);
  `waitForCard` services the jam watch while polling.
- `abortCommand(reason)` — stops the feeder, returns everything to neutral,
  and replies `{"error":"aborted: jam detected","aborted":true}` (with the
  command id).
- New `{"ping": true}` → `{"status":"pong"}` liveness command.

**Web app — `use-serial.tsx`**
- Heartbeat: pings the firmware every 10 s (5 s timeout) while connected and
  ready; a missed pong shows a "Device unresponsive" warning toast once per
  unresponsive stretch and clears on recovery.

### Behavior notes

- No false positives in normal routing: gate presence is transient during a
  ~2 s route, far below the 20 s jam threshold.
- Needs a bench test: timing behavior is unchanged (same delay values), only
  now interruptible.

### How to revert

```bash
git restore arduino/main/main.ino

git restore packages/web/src/features/scanner/api/use-serial.tsx
```

Re-upload the firmware.

---

## Item 11 — Local PostgreSQL hosting + regenerated migration baseline (database)

**Status:** implemented, uncommitted.

### Why

The checked-in drizzle migrations (0000–0010) predated the org-scoping rewrite:
they created only 6 tables with a legacy Supabase-style `user_id`/`auth.user_id()`
model, while `schema.ts` models 13 org-scoped tables. A fresh `db:migrate`
produced a broken database (missing `games`, `collections`, `collection_cards`,
`feeder_configs`, audit tables, `org_id`/`game_key`/`max_capacity` columns), and
the app could only run against hosted Neon because the Neon serverless driver
speaks Neon's WebSocket proxy protocol. We wanted the whole stack to run on a
local machine with no admin rights or Docker.

### What changed

- **Migration baseline regenerated.** Deleted the stale 0000–0010 SQL + meta
  snapshots (backed up) and regenerated a single `drizzle/0000_public_pandemic.sql`
  from `schema.ts`: all 13 tables, 52 org-scoped RLS policies, the per-game
  `(game_key, scryfall_id)` card uniqueness (was global on `scryfall_id`, which
  silently swallowed per-game sync conflicts), calibration defaults aligned with
  the shared constants, and the query-path indexes (`bins.bin_set`,
  `collection_cards.collection_id`/`scryfall_id`, `cards.game_key`, and an HNSW
  index on `cards.embedding`).
- **DB driver swapped.** `packages/server/src/db/index.ts` now uses the standard
  `pg` driver + `drizzle-orm/node-postgres` instead of `@neondatabase/serverless`
  (WebSocket-only; can't reach a local Postgres). Works against both local
  Postgres and Neon's TCP endpoint. Removed the `@neondatabase/serverless` /
  `ws` deps from `packages/server/package.json`; added `pg` / `@types/pg`.
- **Local bootstrap.** New `packages/server/sql/local-neon-bootstrap.sql`
  recreates what hosted Neon provisions automatically — `neon_auth.user` /
  `organization` / `member` tables, the `authenticated` role, table privileges
  for it, and the SECURITY DEFINER `auth_is_org_member()` function the RLS
  policies reference — plus a seeded local user/org.
- **Schema fixes while regenerating:** `module_configs` / `feeder_configs` DB
  defaults now match `DEFAULT_CALIBRATION` / `DEFAULT_FEEDER_CALIBRATION` in
  `@magic-vault/shared` (previously 102/307/… and 400/50/150 — a raw insert
  without a payload drove the servos to the wrong positions).
- **README** documents the portable PostgreSQL + pgvector install, the
  bootstrap, and `.env` values.

### Behavior notes

- Running the server locally without hosted Neon Auth means `NEON_AUTH_URL` is
  a placeholder; JWT verification (and therefore login) still needs the real
  Neon Auth URL. DB-backed API routes and RLS are fully testable locally.
- RLS is enforced by the `authenticated` role (verified locally: cross-org
  rows invisible, cross-org inserts rejected). The app's own pool connects as
  the table owner and bypasses RLS by design — org isolation is enforced at the
  route layer (`requireOrg` + org-scoped queries), with RLS as defense-in-depth.

### How to revert

1. Restore the deleted migrations from `C:\Mault Revised\.local\drizzle-backup`
   (or from git history before this commit).
2. Revert `packages/server/src/db/index.ts` to the
   `@neondatabase/serverless` driver and restore the old deps in
   `packages/server/package.json` (`pnpm install`).
3. Delete `packages/server/sql/` and the README Database section.
4. Re-run `db:generate` to rebuild a migration diff if the schema changes
   again; keep the new baseline otherwise.

---

## Item 12 — Remove Neon entirely: self-hosted better-auth (auth + web)

**Status:** implemented, uncommitted.

### Why

Neon Auth is a hosted wrapper around `better-auth`, but it still forced every
login through the internet (JWKS verification, hosted auth UI) and kept the
project depending on a third-party service. The vision side was already local
(SigLIP via `@huggingface/transformers`); this removes the last online
dependency — auth — by self-hosting the identical better-auth library against
the local Postgres.

### What changed

- **Server — new auth instance.** `packages/server/src/lib/auth.ts` builds a
  better-auth instance with email/password, the `organization` plugin, the
  `emailOTP` plugin (OTP codes are logged to the server console — no email
  provider, fully local), and the `bearer` plugin. Mounted at `/api/auth/*` in
  `packages/server/src/index.ts`.
- **Server — token verification.** `packages/server/src/middleware/auth.ts` no
  longer fetches a JWKS from Neon; it validates `Authorization: Bearer` tokens
  via `auth.api.getSession` against the local `session` table. `getUserRole` /
  `getUserDisplayName` / `requireOrg` now read the better-auth `user` and
  `member` tables instead of `neon_auth.*`.
- **DB — auth tables.** Added `user` (with a `role` column), `session`,
  `account`, `verification`, `organization`, `member`, and `invitation` tables
  to `packages/server/src/db/schema.ts`; regenerated the migration baseline
  (now 20 tables). RLS `auth_is_org_member()` reads the better-auth `member`
  table; the bootstrap runs before AND after `db:migrate` (function/role first,
  grants after) and sets default privileges for future tables.
- **Web — client swap.** `packages/web/src/lib/auth/client.ts` now uses
  `createAuthClient` from `better-auth/react` with the organization + email-OTP
  plugins (Neon's own adapter was a better-auth adapter). Replaced the Neon
  `SignedIn`/`RedirectToSignIn`/`AuthView`/`AccountView`/`UserButton`/
  `NeonAuthUIProvider` with local equivalents (custom sign-in/sign-up/forgot
  password page, account page, sign-out buttons, session-based guards). All
  org hooks (`useListOrganizations`, `useActiveOrganization`, `organization.*`)
  map 1:1. Removed the `@neondatabase/neon-js` dependency and the Neon tailwind
  import. Pinned `better-auth` to the same version (1.4.6) in web and server.
- **Env/docs.** `.env` / `.env.example` now use `BETTER_AUTH_SECRET` (no Neon
  vars); README updated.

### Behavior notes

- **Everything is local now**: DB, auth, and vision. Only card-data sync
  (Scryfall/Gundam/Pokémon), Discord webhooks, and the one-time HuggingFace
  model download need the internet.
- Email OTP codes print to the API server console (`[auth] OTP for …`). For a
  single-user sorter this is the practical offline delivery mechanism.
- Existing users/orgs are stored in the better-auth tables; first sign-up
  creates a `role: user` account (the admin panel gate reads this role).

### How to revert

1. `git checkout` the pre-Item-12 versions of `lib/auth/client.ts`,
   `lib/auth/session.ts`, `router.tsx`, `main.tsx`, the auth/account/nav pages,
   `use-organization.tsx`, the org components, `hooks/use-role.ts`, and
   `use-collection-locks.tsx`.
2. Restore `@neondatabase/neon-js` in `packages/web/package.json` and the
   Neon tailwind import in `src/index.css`.
3. Server: delete `packages/server/src/lib/auth.ts`, restore the JWKS
   verification in `middleware/auth.ts`, and the `neon_auth.*` queries in
   `routes/collections.ts`.
4. Drop the 7 auth tables from `schema.ts` and regenerate the migration.

---

## Item 13 — Remove auth entirely: fully-local single-user build (auth + web)

**Status:** implemented, uncommitted.

### Why

The app is intended to run locally (browser, Arduino, camera, and model all on
one PC) with no remote access. Logins, organizations, and email verification
were pure overhead — they required a sign-in ceremony and leftover cloud
plumbing for zero benefit. This removes the whole auth layer so the app opens
straight into the scanner.

### What changed

- **Server — no-op auth.** `packages/server/src/middleware/auth.ts` now always
  treats every request as the same local operator: `LOCAL_USER_ID`
  (`local-user`), `LOCAL_ORG_ID` (`local-org`), admin role, owner org role.
  `requireAuth`/`requireOrg`/`requireRole`/`requireOrgRole` just set those
  fixed values and pass through. `verifyToken` always succeeds.
- **Server — removed the auth endpoints.** Deleted
  `packages/server/src/lib/auth.ts` (better-auth instance) and its
  `/api/auth/*` mount in `index.ts`. The SSE routes (`/collections/stream`,
  `/collections/lock-events`, `/admin/sync/stream`) no longer require
  `?token=` — they use the fixed org.
- **Server — dropped the 7 auth tables** (`user`, `session`, `account`,
  `verification`, `organization`, `member`, `invitation`) from
  `packages/server/src/db/schema.ts` and regenerated the migration baseline
  (now 13 tables). `auth_is_org_member()` in the bootstrap now just checks the
  org_id claim (no membership table).
- **Web — removed the auth UI.** Deleted the sign-in/sign-up/forgot-password
  page, verify-email page, account page, email-verification banner, and the
  org switcher / picker / settings components. `useRole()` always returns
  admin; `useOrg()` returns the single local org; the nav has no sign-out or
  org menu. Router has no auth guard and no `/auth/*` routes; landing/build
  CTAs link straight to `/app`.
- **Web — no token in API calls.** `getAuthHeaders()` sends only the fixed
  `X-Org-Id: local-org`; the SSE clients and sync stream no longer build
  `?token=` URLs. Removed the `better-auth` dependency from both packages.

### Behavior notes

- Opening `http://localhost:5173` goes straight to the app — no login.
- The `org_id` scoping remains in the DB and queries (single org), so RLS and
  the existing code paths are untouched; the UI just never asks for an org.
- Card data sync, card art, and optional Discord webhooks still need the
  internet; scanning, vision, and everything else are fully local.

### How to revert

1. Restore `packages/server/src/middleware/auth.ts` from before this item, and
   re-add `packages/server/src/lib/auth.ts` + the `/api/auth/*` mount.
2. Restore the 7 auth tables in `schema.ts` and regenerate the migration.
3. Restore `better-auth` in both `package.json`s (`pnpm install`).
4. Web: restore `lib/auth/client.ts` (authClient) and `lib/auth/session.ts`;
   re-add the auth/account/verify-email/org pages and the router guards.

---

## Item 14 — Local-first card art and sync catalog cache (web + database)

**Status:** implemented, committed with the local build.

### Why

The app should work offline once data is in place. Two remaining online paths
were needless: the card grid always fetched art from Scryfall/Gundam/Pokémon
hosts even though every scanned card already has a webcam capture, and every
sync re-downloaded Scryfall's multi-hundred-MB bulk catalog even when nothing
had changed upstream.

### What changed

- **Web — scanned card art is local-first.** `ScannedCardItem` takes an optional
  `capturedImageUrl` (the webcam capture, already stored in
  `collection_cards.captured_image_data_url`) and renders it instead of the
  online art when present, falling back to `getCardImageUris()` only when a
  scan is missing. The grid passes the capture through; the detail panel shows
  the capture as the main art for the scanned card (online art still shown for
  corrected/alternative candidates).
- **Server — sync catalog cache.** `packages/server/src/lib/sync-cache.ts`
  stores the downloaded Scryfall bulk catalog (`packages/server/.cache/sync`)
  keyed by the catalog's `updated_at`. On re-sync the server first fetches the
  tiny bulk-data index, and when the version is unchanged it loads the catalog
  from disk instead of re-downloading the ~GB file. New cards are still
  detected because the sync always compares against the cached catalog; only
  cards without an embedding are vectorized.
- **Server — art proxy disk cache.** `/api/cards/image-proxy` now stores every
  fetched image in `packages/server/.cache/art` (keyed by SHA-256 of the URL)
  and serves previously-viewed art from disk with no network call. Cache
  locations are overridable via `SYNC_CACHE_DIR` / `ART_CACHE_DIR` (see
  `.env.example`).

### Behavior notes

- First sync still downloads the full catalog once; subsequent syncs skip the
  download until Scryfall publishes a new version (roughly daily).
- Card art for cards that have been viewed before works offline; brand-new
  art still needs one fetch to populate the cache.
- The webcam capture is what the vision model matched on, so the grid now
  shows the physical card as scanned — glare/angle and all.

### How to revert

1. Web: remove the `capturedImageUrl` prop plumbing in `ScannedCardItem`/
   `card-grid.tsx`/`card-detail-panel.tsx` and restore the `getCardImageUris`
   art.
2. Server: delete the cache checks in `lib/scryfall/sync.ts` and
   `routes/card.ts`, and remove `lib/sync-cache.ts`.
3. Optionally delete `packages/server/.cache/` to drop stored catalogs/art.

---

## Item 15 — Local card hydration + SigLIP benchmark (server)

**Status:** implemented, uncommitted.

### Why

Scanning re-fetched full card details from the remote card API on every
first encounter of a card (1-hour in-memory cache only). That put 0.5–1.5 s of
variable network latency in the scan path and made scanning depend on the
internet. The card data is already in the bulk sync — it was being thrown away.

### What changed

- **DB — `cards.card_data`.** New `card_data jsonb` column (migration
  `drizzle/0001_pale_jack_murdock.sql`). Stores the complete card object.
- **Sync — populate card data.** `SyncSourceCard` gained `cardData`; the
  Scryfall sync now keeps the full card object from `unique_artwork` instead of
  discarding it. `sync-job.ts` stores it on insert and backfills rows that
  predate the column (batched, next sync run). Gundam/Pokémon bulk lists don't
  carry full card objects, so those games populate on first scan instead.
- **Hydration — DB first, network last.** `resolveCardDetails` now takes
  `gameKey` and serves from the in-memory cache → local DB → remote adapter.
  A remote fetch is persisted back into `cards.card_data` (update-only, never
  inserts junk rows), so each card is fetched from the network at most once
  ever. Verified end-to-end with a smoke test (fetch → persist → local hit).
- **Benchmark — `pnpm bench:vectorize`.** `packages/server/scripts/bench-
  vectorize.ts` times the real scan-path embed (JPEG decode + preprocess +
  model) and reports min/p50/mean/p95 + cards/sec.

### Benchmark results (this machine, SigLIP base 512 q8, CPU)

- Full scan-path embed: **~703 ms** (p95 714 ms)
- Model forward only: **~648 ms** (decode/preprocess is only ~55 ms)
- Throughput ceiling ≈ **1.4 cards/sec** of pure compute

With the search overlapping the physical sort, the 2 s/card target is roughly
achievable on shallow bins (1–4); deep bins (5–6) and any search slower than
the sort push it over. Margin requires a smaller model (e.g. 224 px — cheaper
but needs a re-sync) or faster hardware.

### Behavior notes

- After the next MTG sync, card details are served entirely from Postgres —
  no network in the scan path for synced cards.
- New cards printed after a sync still hydrate once from the API, then stay
  local.
- The `cards` table is currently empty on this machine — **no sync has been
  run yet**. The first sync (admin UI) is required before scanning can match
  anything; it downloads the catalog once and embeds ~25k MTG cards (hours,
  one time).

### How to revert

1. Drop `card_data` from `schema.ts` and generate a migration; or delete
   migration `0001_pale_jack_murdock.sql` and `ALTER TABLE cards DROP COLUMN
   card_data`.
2. Restore `card-cache.ts` to the remote-only version and the old
   `resolveCardDetails` signature in `routes/card.ts`.
3. Remove the `cardData` plumbing from `sync-types.ts`, `scryfall/sync.ts`,
   and `sync-job.ts`.

## Item 16 — GPU (DirectML) acceleration for vision embeddings (server)

**Status:** implemented, uncommitted.

### Why

SigLIP embeddings (the per-scan compute) took ~703 ms on CPU. The machine
has a Quadro M4000; onnxruntime-node already bundles DirectML.dll on Windows,
so the GPU path needed no installs — just a device switch.

### What changed

- **`VECTORIZE_DEVICE` env var** (`cpu` default, `dml` for GPU).
  `lib/vectorize.ts` picks the device + dtype and logs both at load.
- **q8 + DirectML crashes natively** (access violation, confirmed) — so dtype
  is forced to fp32 whenever DML is selected; the q8 model stays the CPU path.
- `.env` on this machine sets `VECTORIZE_DEVICE=dml`; `.env.example` documents
  both options.

### Benchmarks (this machine)

| Path | Device | Embed time | Throughput ceiling |
|---|---|---|---|
| q8 | CPU | ~703 ms | 1.42 cards/sec |
| fp32 | DirectML (M4000) | ~375 ms | 2.67 cards/sec |

≈**1.9× faster**. With the search now ~380 ms (+300 ms settle + encode), it
overlaps shallow-bin sorts with comfortable margin, putting the 2 s/card
target under budget instead of right at it. The bulk sync also embeds ~1.9×
faster (hours saved on the one-time MTG run).

### Behavior notes

- First model load on dml downloads the fp32 weights once (374 MB, cached in
  the transformers.js cache dir); later loads are ~1 s.
- First embed after a server start includes one-time session init (~1.1 s),
  then steady state. On a cold machine with uncached weights, first boot
  takes a few minutes.

### How to revert

1. Remove `VECTORIZE_DEVICE` from `.env` / `.env.example`.
2. Revert `lib/vectorize.ts` to the q8-only load.

## Item 17 — Holo/foil detection v1 (heuristic, web)

**Status:** implemented, uncommitted.

### Why

Holo vs non-holo was a purely manual toggle. Long-term this feeds card
identity for DBZ/One Piece (foil is a different product there), and even for
MTG it saves the operator a correction per foil card.

### What changed

- **`packages/web/src/features/scanner/lib/foil-detect.ts`** — heuristic that
  scores the warped scan crop (the same canvas that gets uploaded, so no
  extra decode or round trip). Features: circular hue variance (rainbow),
  saturation variance (iridescence), value variance + bright coverage
  (specular highlights), and edge energy (sparkle). Returns a 0..1 score;
  `FOIL_SCORE_THRESHOLD = 0.5` is a calibration starting point.
- **Wired through the scan path**: `searchCardImage` computes the score on
  the crop, `onSearchResults` carries `isFoil`, and `addCard` pre-fills the
  card's `isFoil` flag. The detail-panel toggle still lets the operator
  correct it — corrections persist to `collection_cards.is_foil` alongside
  `captured_image_data_url`, which **automatically collects labeled training
  data** for the v2 classifier.
- Pixel core is exported for testing; synthetic smoke test: matte 0.001 vs
  rainbow 0.379.

### Behavior notes

- Heuristic thresholds MUST be calibrated against real captures once the rig
  is built (`custom/PLAN.md` commissioning checklist item 5). Until then it
  may over- or under-detect; corrections are expected and are exactly what
  trains v2.
- v2 = small classifier on the SigLIP embedding or crop, trained on the
  accumulated labeled scans. No extra model download at scan time.
- Hardware assist (angled second light, two captures) remains a future
  near-perfect option.

### How to revert

1. Delete `lib/foil-detect.ts`.
2. Remove the `isFoil` threading from `use-card-scanner.ts`,
   `card-scanner.tsx`, `use-scanned-cards.tsx`, and the `onSearchResults`/
   `addCard` signatures.

## Item 18 — Scan light + two-frame holo detection (firmware + web)

**Status:** implemented, uncommitted.

### Why

Single-frame holo heuristics are the weakest link in foil detection. The
physical signature is angle-dependent: a holo changes COLOR with the light
angle (diffraction grating), a matte card only gets brighter. A toggleable
angled light makes that discrimination nearly deterministic — and the
PCA9685 already had the wiring spots.

### What changed

- **Firmware — LED 5 on PCA9685 ch14.** `{"led": 5, "on": bool}` (range
  extended 4 → 5); header comment + SERIAL_PROTOCOL.md updated.
- **Web — two-frame scan with smart skip.** `foil-detect.ts` adds
  `computeFoilDifferenceScore` (hue/saturation shift fraction between frames)
  and `shouldUseSecondFrame` (frame A below `FOIL_SECOND_FRAME_THRESHOLD` =
  clearly matte → skip the light + second picture entirely). `searchCardImage`
  orchestrates: frame A (light off) → score → if ambiguous: toggle scan light
  (`toggleScanLight` prop, wired to `{"led":5}` via `useSerial`), 120 ms
  settle, frame B (light on) → chroma-difference decision → light off. The
  lit frame doubles as the upload/match image (better illumination).
- **Fallback:** no serial connection → single-frame heuristic (v1) as before.
- **Docs:** BUILD.md scan-light wiring (LED + resistor on ch14, angled mount),
  SERIAL_PROTOCOL.md LED 5.

### Behavior notes

- Most cards (matte) cost one picture + no light toggle. Only holo-looking
  frames trigger the second capture (~200 ms extra, hidden under the sort).
- Thresholds (`FOIL_SECOND_FRAME_THRESHOLD`, `FOIL_DIFF_THRESHOLD`) are
  calibration starting points for when the rig is built.

### How to revert

1. Firmware: revert the LED range to 4.
2. Web: remove `toggleScanLight` from `CardScannerProps`/`useCardScanner` and
   the two-frame branch in `searchCardImage`.

---

## Item 19 — Config-driven multi-TCG adapter: Yu-Gi-Oh! + Digimon (server)

**Status:** implemented, uncommitted.

### Why

Adding a TCG previously meant duplicating the whole search/sync/normalize
adapter (Pokémon pattern). With DBZ/One Piece and others coming, that doesn't
scale. Most TCG databases expose the same JSON shape; only the URLs and field
mapping differ.

### What changed

- **`lib/card-search/generic.ts`** — `createSearchAdapter(config)` +
  `createSyncSource(config)` factory. Config = search URL, optional by-id
  URL (else bulk-catalog filter), bulk URL, result-path extractor, and
  field-mapping functions. Ships `baseCard()`, `imageUris()`, `str()/num()`
  helpers and a complete PlayingCard shape so configs stay ~40 lines.
- **`lib/card-search/generic-configs.ts`** — `yugiohConfig` (YGOPRODeck) and
  `digimonConfig` (digimoncard.io). Both endpoints verified live:
  search, by-id, bulk, and image hosts.
- Registered in `resolve.ts` (search) + `sync-job.ts` (sync) as `yugioh` and
  `digimon`; image hosts added to the proxy allowlist in `routes/card.ts`.
- Sync stores the **normalized** card in `cards.card_data`, so hydration
  serves the correct PlayingCard shape for the new games.

### Behavior notes

- Add the game row in the web admin UI (Settings → Games) with key `yugioh` /
  `digimon`, then run its sync once (bulk embed; YGO ~13k cards, Digimon
  ~9k — one-time, hours on this machine, resumable).
- Top-20 TCG plan + per-game data-source status: `custom/TCGS.md`.

### How to revert

1. Remove the `yugioh`/`digimon` registrations from `resolve.ts`,
   `sync-job.ts`, and the allowlist in `routes/card.ts`.
2. Delete `generic-configs.ts` and `generic.ts`.

## Item 20 — Dataset importer for no-API TCGs (server)

**Status:** implemented, uncommitted.

### Why

Research (2026-08) found One Piece and Dragon Ball Super/Fusion World have
**no clean, hosted, public JSON API** — optcgdb's API gateway rejects direct
access, the official sites have no API, dbscards.com is a static site, and
fabdb.net is unreachable from this machine. Community sources distribute those
games' data as files, so a file importer completes the architecture.

### What changed

- **`packages/server/scripts/import-cardset.ts`** — ingests a JSON array of
  card objects: field-mapping file (dotted paths; `imageUrl` or
  `imageTemplate` with `{id}`), embeds art with the local SigLIP model, stores
  rows in `cards` (embedding + normalized `card_data`). Works offline after
  the one-time import. Verified end-to-end with a real YGOPRODeck export
  (2 cards embedded, rarity preserved, cleaned up after).

```bash
cd packages/server
npx tsx --env-file ../../.env scripts/import-cardset.ts \
  <gameKey> <cards.json> [--map mapping.json] [--limit N]
```

### Behavior notes

- Onboarding One Piece/DBZ = obtain a trusted dataset file, write the ~5-line
  mapping, run once. `custom/TCGS.md` has the updated source status matrix.

### How to revert

1. Delete `scripts/import-cardset.ts`.

## Item 21 — Value-based binning + local runbook (shared + server + docs)

**Status:** implemented, uncommitted.

### Why

Sorting by card value (e.g. "over $2 → reject bin") is a requested sort
axis. The binning engine already supported numeric rules; what was missing was
the foil-price field and price data for the generic-config games. Also: the
machine had never been set up (empty DB, web server not running), so the
one-time first-run flow needed documenting.

### What changed

- **`price_usd_foil` bin field** added to `FIELD_DEFINITIONS` (path
  `prices.usd_foil`) so foil-value sorting works alongside the existing
  `price_usd` field. Price rules (`gt`/`gte`/`lt`/`lte`/`equals`) already
  existed — a rule like `Price (USD) greater than 2` routes a card to
  whatever bin (including a dedicated reject bin) the operator configures.
- **Yu-Gi-Oh! prices wired**: YGOPRODeck `card_prices` → `prices.usd`
  (tcgplayer) and `prices.eur` (cardmarket) in `yugiohConfig`.
- **`scripts/start-web.cmd`** — detached launcher for the Vite dev server;
  the web UI is now running at http://localhost:5173.
- **`custom/SETUP.md`** — runbook: URLs, start/stop, first-run steps (games →
  collection → bins → sync), value-sort how-to, price-source table, known gaps.

### Behavior notes

- Price data availability: MTG ✅ (Scryfall bulk), Yu-Gi-Oh! ✅, Gundam /
  Pokémon / Digimon ❌ (sources carry no prices) — value rules are inert for
  those games until a price source is added.
- The `cards` table is empty on this machine: the first MTG sync (Admin page)
  is required before scanning can match anything.

### How to revert

1. Remove `price_usd_foil` from `FIELD_DEFINITIONS`.
2. Remove the `card_prices` mapping from `yugiohConfig`.
3. Delete `scripts/start-web.cmd` and `custom/SETUP.md`.

## Item 22 — First-run setup executed: seed script + default data (server + web)

**Status:** implemented, committed.

### Why

The machine had never been set up — the DB was completely empty (0 games, 0
collections, 0 bin sets), so the app was unusable until the operator clicked
through Settings → Games, Collections, and Bins by hand. The task was to make
the first-run path one command and to run it.

### What changed

- **`packages/server/scripts/seed-local.ts`** — idempotent seeder: upserts the
  five sync-capable game rows (`mtg`, `yugioh`, `digimon`, `gundam`, `pokemon`)
  with their real data-source URLs and per-game rarity field definitions;
  creates a default active collection (`My Collection`, MTG); creates an active
  7-bin set (bin 7 = catch-all); creates a ready-made `Standard Bundle
  (15/15/5/5)` config. Safe to re-run.
- **Default data created on this machine** via the script (verified through the
  API): 5 games, 1 collection, 1 bin set, 1 bundle config.
- **`custom/SETUP.md`** updated: first-run is now `npx tsx
  scripts/seed-local.ts` + one card sync in Admin (still required — the `cards`
  table stays empty until sync embeds a catalog).

### How to revert

1. Delete the seeded rows (`DELETE FROM bundle_configs/bins/bin_sets/collections/games`).
2. Remove `scripts/seed-local.ts` and the SETUP.md first-run section.

## Item 23 — Yu-Gi-Oh! / Digimon search adapters registered (server)

**Status:** implemented, committed.

### Why

Item 19 wired YGO/Digimon into the **sync** path (`SYNC_SOURCES`) but never into
`ADAPTERS_BY_GAME_KEY` in `resolve.ts` — the search adapter map only had
mtg/gundam/pokemon. Scanning cards for a Yu-Gi-Oh! or Digimon collection would
fail at search time (`resolveCardSearch` returns null), and the dataset
importer's per-card hydration uses the same resolution.

### What changed

- `packages/server/src/lib/card-search/resolve.ts` now includes
  `yugioh: createSearchAdapter(yugiohConfig)` and
  `digimon: createSearchAdapter(digimonConfig)`.

### How to revert

1. Remove the two entries from `ADAPTERS_BY_GAME_KEY`.

## Item 24 — Bundle mode: fixed-composition runs with no duplicates (full stack)

**Status:** implemented, committed.

### Why

The machine's primary job is assembling card bundles (e.g. 15 common / 15
uncommon / 5 rare / 5 super-rare, operator-selectable). That needs: per-rarity
target counts with per-bin routing, a no-duplicates rule across the whole run,
a reject bin for duplicates/overflow/unmatched rarities, and resume support so
a restart doesn't lose the run.

### What changed

- **DB** — migration `0002_bundle_mode`: `bundle_configs` (name, targets jsonb
  `[{rarity, count, binNumber}]`, reject_bin_number, is_active) and
  `bundle_runs` (config FK cascade, status active/completed/aborted,
  placed_card_ids jsonb, counts jsonb), org-RLS like every other table.
- **Server** — `packages/server/src/routes/bundles.ts` (mounted at
  `/api/bundles`): CRUD for configs; start/abort/complete a run; `GET
  /run/active` (resume lookup); `POST /run/:guid/place` is the authoritative
  decision point — duplicate / unmatched-rarity / target-full → reject bin,
  else accept into the target bin, persist counts + placed ids, auto-complete
  when all targets are met.
- **Shared** — `bundles.interface.ts` types (`BundleTarget`, `BundleConfig`,
  `BundleRun`, `BundlePlaceResult`).
- **Web** — `BundlesProvider` (configs + active run + optimistic mirror of
  placements) and a `BundlePanel` on the scanner page: live progress (per-rarity
  count/target bars), start/abort, and a config editor (name, rarity/count/bin
  rows, reject bin). `use-scanned-cards.tsx` `addCard` routes through the active
  run when one exists — the run decides the bin, the scan record is still
  persisted as normal, bundle-complete pauses auto-feed.

### Behavior notes

- Duplicate rule uses the card id (`card.id`). Foil prints that are a different
  product id (DBZ/One Piece) count as distinct cards; MTG foils share the id and
  a second copy is rejected — exactly the "no 2 the same" behaviour.
- Bundle configs are org-global (no game binding) — target rarities must match
  the cards being scanned (e.g. YGO "super rare" ≠ MTG "mythic").
- If the API is unreachable mid-run, a card routes to the reject bin (safe
  failure — a bundle bin is never polluted) and bundle state is unchanged.

### How to revert

1. Drop migration `0002_bundle_mode` (tables + policies).
2. Remove `bundlesRouter` mount, the bundles route file, the provider/panel,
   and the bundle branch in `addCard`.
3. Remove `bundles.interface.ts` + its index export.

## Item 25 — Fix MTG card sync: Scryfall JSONL format + parallel fetch/batch embed (server)

**Status:** implemented, committed.

### Why

Clicking the Admin sync for Magic: The Gathering died immediately with `Fatal
error: Failed to parse URL from undefined`. Scryfall changed their bulk-data API:
entries no longer carry `download_uri` — the catalog now points at a gzipped
**JSONL** file via `jsonl_download_uri`, and the sync tried to `fetch(undefined)`
and then `res.json()` a JSONL payload it couldn't parse. Separately, once the
parse was fixed the sync ran at ~6s/card (a full 54k-card catalog would have
taken ~90 hours) because images were fetched one at a time from a host that
throttles per-connection.

### What changed

- **`scryfall/sync.ts`** — resolves `jsonl_download_uri` (with `download_uri`
  fallback), gunzips the bulk file when gzipped, and parses both formats
  (JSONL lines and the legacy JSON array). A single malformed line is skipped
  rather than failing the whole download. Fetches the `large` (JPG) size — same
  pixel dimensions as PNG but 5-7x fewer bytes, and the connection-throttled
  host makes transfer size the bottleneck.
- **`sync-job.ts`** — images are fetched in **parallel batches of 16** (the CDN
  allows parallel connections; measured 16 in the same wall time as 1) and
  **pipelined** (next chunk fetches while the current chunk embeds). Embeddings
  use a new **`vectorizeBuffers`** batch path (`vectorize.ts`) that runs N
  images in one model forward (~1.4x faster than N singles).
- **GPU safety**: batch-16 embeddings crashed the DirectML device on the Quadro
  M4000 (`DXGI_ERROR_DEVICE_HUNG`), so fetch batch (16) and embed batch (8)
  are decoupled. A GPU-hang guard aborts the sync with a clear “restart the
  server” message instead of churning per-card errors.

### Behavior notes

- Measured on this machine: **~0.6s/card, 0 errors** sustained (was 6s/card).
  The full 54k-card MTG catalog is a one-time ~9-10 hour run; the sync is
  resumable (skips cards already in the DB) and the bulk catalog is cached to
  disk keyed by Scryfall's `updated_at`.

### How to revert

1. Restore `download_uri` parsing and `res.json()` in `scryfall/sync.ts`.
2. Remove `vectorizeBuffers` and the parallel/pipelined loop in `sync-job.ts`.

## Item 26 — Hardware diagnostics: servo wiggle test + scan light control (web)

**Status:** implemented, committed.

### Why

Before trusting any routing, a freshly built machine needs to prove each servo
is wired to the right channel and each bin route fires the right mechanism.
The calibration page already had per-servo jog controls (±1/±10 raw PWM) and
“Set” buttons for calibration points, but nothing that guides an operator
through verifying the hardware, and the scan light (LED 5) couldn't be toggled
from the UI even though the firmware supports it.

### What changed

- **`servo-diagnostics.tsx`** (new, on `/app/calibrate`) — a commissioning
  panel that lists all 9 servos (3 modules × bottom/paddle/pusher) with their
  job (“trapdoor — drops the card to the next module”, “gate — holds the card
  while the pusher ejects it”, “pusher — ejects left/right”), which bins each
  one participates in, and a **Wiggle** button that cycles the servo between
  its two calibrated extremes (2×) and back to rest so the operator can watch
  the physical part and confirm the wiring. “Wiggle all” runs a module's three
  servos in sequence.
- **Bin route map** — a table of bins 1–7 → the exact mechanical sequence each
  route runs (mirrors `routeCard()` in `main.ino`), so testing a bin shows what
  should be moving.
- **`led-controls.tsx`** — added the **Scan Light** toggle (LED 5, firmware
  channel 14) alongside LEDs 1–4; the page hook now tracks five LED states.

### Behavior notes

- Wiggling uses the calibrated pulse values (falls back to defaults when a
  module is unconfigured) and returns each servo to its resting position
  (closed for bottom/paddle, neutral for pusher).
- Combine with the existing tools on the page: ±1/±10 jog to find the exact
  start/end pulses, “Set” to save them as calibration points, then “Run Test”
  for the full sweep and the bin test panel for a complete sample run.

### How to revert

1. Remove `<ServoDiagnostics />` from `calibrate.tsx` and delete the component.
2. Remove the Scan Light button from `led-controls.tsx` and the 5th LED state.

## Item 27 — Pokémon sync fix + auto-advancing sync queue (server + web)

**Status:** implemented, committed.

### Why

Two things: (1) the Pokémon sync silently did nothing — TCGdex's list endpoint
only returns `{id, localId, name}`, no image, so every card was skipped as
“no imageUrl” and the DB would never get a single Pokémon card; (2) syncing
five games one at a time meant babysitting the Admin page for hours, clicking
“Start Sync” again after each finished.

### What changed

- **Pokémon sync** (`pokemon/sync.ts`) — `fetchCards` now enriches every list
  entry with a detail fetch (bounded concurrency 16), which provides the real
  image URL, rarity, and set. The normalized PlayingCard is stored as
  `cardData`, so Pokémon gets rarity binning, bundle recipes, and offline
  hydration like every other game. `fetchDetail` double-encodes ids so the
  punctuation-variant cards (`exu-%3F` Unown, etc.) resolve too.
- **Sync queue** (`sync-job.ts` + `admin.ts`) — `POST /api/admin/sync/queue`
  queues game keys that run one at a time (they share the GPU); when a run
  completes, cancels, or fails, the next key starts automatically. `GET`/
  `DELETE` endpoints expose/clear the queue. The Admin page gained a **Sync
  All Games** button that queues every sync-capable game.

### Behavior notes

- Current queue on this machine: Pokémon → Yu-Gi-Oh! → Digimon → Gundam
  (~8 h total at ~0.6 s/card on the GPU).
- Pokémon's detail enrichment adds ~5–10 min of catalog fetching before the
  embedding phase starts.

### How to revert

1. Remove the enrichment loop from `pokemon/sync.ts` and the encode fix in
   `fetchDetail`.
2. Remove the queue functions from `sync-job.ts`, the queue endpoints from
   `admin.ts`, and the Sync All button.

## Item 28 — Card Library browser (server + web)

**Status:** implemented, committed.

### Why

The synced card database had no real browsing UI — only a bare text list in
Admin (name + set code, no art, no filters). The library is the payoff of the
sync work, so it should be browsable like a collection.

### What changed

- **`GET /api/cards/library`** (new, in `routes/card.ts`) — paginated card
  browsing with filters: `gameKey`, name `search` (ILIKE), `rarity` and `set`
  (both extracted from the stored `card_data` jsonb). Returns art URL + rarity
  + set name + the full card object so detail views need no second request.
- **`/app/library` page** (new) — art grid (lazy-loaded thumbnails) with game
  tabs (All / Magic / Pokémon / Yu-Gi-Oh! / Digimon / Gundam), debounced name
  search, a per-game rarity dropdown (from the game's field definitions), a set
  code filter, and “Load more” pagination. Clicking a card opens a detail panel
  (large art, rarity badge, type line, collector number, prices, oracle text).
- **Nav** — new Library item in the sidebar.

### Behavior notes

- Art is served through the existing local image proxy, so re-viewing a card
  is instant/offline once its art is cached.
- The rarity dropdown shows the options seeded for each game; games with
  rarities outside those options can still be found via search/set filters.

### How to revert

1. Remove the `/library` route from `card.ts`.
2. Delete `packages/web/src/app/routes/app/library.tsx`, the library feature
   folder, the route entry, and the nav item.

## Item 29 — Bundle holo/duplicate toggles + physical bin capacity limits (shared + server + web)

**Status:** implemented, committed.

### Why

Two needs from the operator: (1) bundles shouldn't always care about holo — a
plain common bundle is fine with a holo common mixed in, and some bundles need
to allow repeated copies of the same card; (2) the machine's bins have fixed
physical heights (155 mm at module 1 nearest the feeder, 110 mm module 2,
65 mm module 3, 60 mm reject), so each bin needs a card limit computed from
real card thickness to guarantee no overflow.

### What changed

- **Bundle toggles**: `bundle_configs` gained `allow_duplicates` and
  `holo_detection` (migration `0003_bundle_toggles`). Each rarity target also
  carries an optional `foil` filter (`any` / `foil` / `nonfoil`). When holo
  detection is off, the scan's foil signal is ignored — a holo common and a
  plain common are both just “common”. When on, targets can be split by foil
  (e.g. “common non-foil ×15 → bin 1” and “common foil ×1 → bin 2”), and a
  card whose foil status matches no same-rarity target rejects with
  `foil-mismatch`. `allowDuplicates` skips the no-duplicates check. The
  bundle editor (Bundle Mode panel) exposes both toggles and the per-target
  foil selector; the scan path passes the two-frame foil verdict into the
  bundle decision.
- **Bin capacities**: shared constants `BIN_HEIGHTS_MM` (1–2: 155, 3–4: 110,
  5–6: 65, 7: 60), `CARD_THICKNESS_MM = 0.3`, and
  `maxCapacity = floor((height / 0.3) × 0.9)` (10 % headroom so a full stack
  never jams against the mechanism). Applied to the default bin set by
  `scripts/apply-bin-capacities.ts` (bins 1–2: 465, 3–4: 330, 5–6: 195,
  reject: 180) and by the seeder for fresh installs. The existing per-bin
  “max capacity” routing check (overflow → catch-all) enforces the limits.

### Behavior notes

- Counts are now keyed by target (`rarity[:foil]`), so two same-rarity targets
  split by foil each track independently.
- When duplicates are allowed, placed-card ids don't accumulate, so progress
  is summed from per-target counts.

### How to revert

1. Drop migration `0003` and the foil logic in `routes/bundles.ts`.
2. Remove the capacity constants/script and reset `maxCapacity` to 0.

## Item 30 — Sound bin-full logic: per-bin status, empty/reset, pause-on-overflow (web)

**Status:** implemented, committed.

### Why

A seller/collector running long batches needs certainty that a bin can never
overflow. Previously a full matched bin fell back to the catch-all, but the
catch-all itself could overflow, and bundle mode ignored physical bin capacity
entirely — rejects piled into the reject bin with no limit. There was also no
way to see per-bin fill or tell the machine “this bin is empty now”.

### What changed

- **Per-bin status + Empty/reset** — the scanner page gained a **Bin Status**
  strip showing every bin's count vs capacity (green/amber/red by fill level,
  catch-all marked `R`) with a per-bin **Empty** button. Emptying a bin resets
  its session count — the confirmation that it was physically emptied.
- **Pause until space exists** — when a card has nowhere to go (matched bin
  full AND catch-all full; bundle destination bin at capacity; reject bin at
  capacity), the machine pauses with a clear “Bin N is full — empty a bin,
  then tap Empty to resume” message and no phantom scan record is saved. The
  card stays at module 1 and is re-scanned after resume.
- **Empty resumes the run** — `emptyBin` clears the pause flag, re-enables
  auto-feed, and feeds the stuck card automatically (a resume hook is wired
  into the scanner so its state returns to scanning).
- **No more silent count resets** — toggling auto-feed no longer wipes all bin
  counts (that would forget cards still sitting in other bins); only the
  per-bin Empty buttons (or clearing the session) reset them.
- Bundle mode now checks physical bin capacity before committing, so a bundle
  whose target count exceeds the bin's physical capacity pauses instead of
  overflowing (bundle targets should stay within the bin capacities in
  `custom/SETUP.md`).

### Behavior notes

- Bin counts are session-scoped (reset on browser reload) — consistent with
  the existing software-capacity model; there are no bin-full sensors.
- When a bundle run completes exactly as its last bin fills, the leftover card
  routes to the reject bin after the operator empties and resumes.

### How to revert

1. Remove `bin-status.tsx` and its page placements.
2. Remove `binCounts`/`emptyBin`/`pauseForFullBin`/resume hook from
   `use-scanned-cards.tsx` and restore `setAutoFeed`'s count reset.

## Item 31 — Bundle live value (shared + server + web)

**Status:** implemented, uncommitted.

### Why

A seller needs to know what a bundle is worth while it's being assembled, not
only after it completes. The bundle run now tracks a running `totalValueUsd`
so the panel can show the value growing in real time.

### What changed

- **Schema** — `bundle_runs.total_value_usd` numeric column (migration
  `0004_chase_wishlist_value.sql`).
- **Shared** — `BundleRun.totalValueUsd: number` in
  `packages/shared/src/interfaces/bundles.interface.ts`.
- **Server** — `routes/bundles.ts` `POST /run/:guid/place` accepts an optional
  `priceUsd`; when present and > 0 it's added to `totalValueUsd`. The value
  persists with the run, so reload/restart resume is exact.
- **Web** — bundle panel shows the running total next to the progress bar;
  `bundles.ts` / `use-bundles.tsx` pass `totalValueUsd` through.

### Behavior notes

- Price comes from the scanned card's `prices.usd` (see "Where prices come
  from" in `custom/SETUP.md` for which games have prices). Cards without a
  price contribute $0.

### How to revert

1. Drop `bundle_runs.total_value_usd` (reverse migration `0004`).
2. Remove `totalValueUsd` from the shared interface and the price
   accumulation block in `routes/bundles.ts`.

---

## Item 32 — Export collection to CSV (web)

**Status:** implemented, uncommitted.

### Why

A collector wants their scanned cards in a spreadsheet (inventory, pricing,
backup) without any export plumbing.

### What changed

- `packages/web/src/features/cards/lib/collection-export.ts` — groups scanned
  cards by card id and renders CSV (name, set, set code, rarity, collector #,
  price USD, qty, foil, bin), with proper quoting.
- `packages/web/src/features/cards/components/card-grid.tsx` — **Export CSV**
  button downloads `collection-<date>.csv`. Exports all scanned cards, not
  just the filtered view.

### Behavior notes

- Foil = “yes” when any scan of that card was foil; Bin comes from the most
  recent scan that reported one.

### How to revert

1. Remove the Export CSV button from `card-grid.tsx`.
2. Delete `collection-export.ts`.

---

## Item 33 — Set completeness view (web)

**Status:** implemented, uncommitted.

### Why

Collectors chase full sets; the library can now answer “how close am I to
finishing this set?” using the cards scanned this session.

### What changed

- `packages/web/src/app/routes/app/library.tsx` — **Set completeness** switch
  on the library page. When on, search/rarity inputs are disabled and a set
  code drives the browse; the header shows `owned / total` and a percentage.
  Owned = scanned-card ids matching the set's cards.

### Behavior notes

- Ownership is session-scoped (scanned cards in the current browser session),
  matching the scanner's count model.

### How to revert

1. Remove the switch + completeness query from `library.tsx`.

---

## Item 34 — Duplicate report (web)

**Status:** implemented, uncommitted.

### Why

For no-duplicate workflows (and bulk resale), knowing which cards were scanned
more than once is the fastest way to find accidental doubles.

### What changed

- `packages/web/src/features/cards/components/duplicates-dialog.tsx` — dialog
  listing every card scanned more than once, with quantity.
- `card-grid.tsx` — **Duplicates** button opens it (all scanned cards, not the
  filtered view).

### How to revert

1. Remove the Duplicates button + dialog from `card-grid.tsx`.
2. Delete `duplicates-dialog.tsx`.

---

## Item 35 — Set-chase mode (server + web)

**Status:** implemented, uncommitted.

### Why

“Chase” a single set: any card from that set that the collection doesn't own
yet routes to a chase bin; owned/duplicate/off-set cards go to the reject bin.
Builds set-complete piles automatically.

### What changed

- **Schema** — `chase_configs` + `chase_runs` tables (migration `0004`),
  org-scoped RLS like every other table.
- **Server** — `packages/server/src/routes/chase.ts` (mounted in `index.ts`):
  CRUD on configs, `POST /:guid/start` / `/abort`, and
  `POST /run/:guid/place` which accepts a card only when its `setCode` matches
  the config, isn't already found this run, and (when a collection is bound)
  isn't already owned. Rejects return `not-in-set` / `duplicate` / `owned`
  with the reject bin.
- **Web** — `ChaseProvider` (`use-chase.tsx`) + **Chase panel** on the scanner
  sidebar; scan routing in `use-scanned-cards.tsx` gives chase priority over
  wishlist and normal bin rules (bundle still wins). Physical bin capacity is
  checked before a chase placement, so a full chase bin pauses the machine.

### Behavior notes

- Chase runs resume after reload/restart (runs persist in Postgres).
- Set code comparison is case-insensitive/uppercased on the server.

### How to revert

1. Drop `chase_configs` / `chase_runs` (reverse migration `0004`).
2. Remove `routes/chase.ts` + mount line, `use-chase.tsx`, `chase-panel.tsx`,
   and the chase branch in `use-scanned-cards.tsx`.

---

## Item 36 — Wishlist routing (server + web)

**Status:** implemented, uncommitted.

### Why

A seller building orders (or a collector chasing singles) wants specific cards
to route to their own bin no matter what the normal bin rules say.

### What changed

- **Schema** — `wishlists` + `wishlist_items` tables (migration `0004`).
- **Server** — `packages/server/src/routes/wishlist.ts` (mounted in
  `index.ts`): CRUD on wishlists and their items; items are a card id or a
  name pattern.
- **Web** — `WishlistProvider` (`use-wishlist.tsx`) + **Wishlist panel** on
  the scanner sidebar. `useScannedCards.matchBin(card, gameKey)` matches an
  active wishlist for the collection's game by card id or name pattern;
  matches override normal bin rules (after bundle + chase). Bin capacity is
  enforced before routing.

### Behavior notes

- A wishlist only fires for the same game as the active collection.
- Name patterns match case-insensitively against the card name.

### How to revert

1. Drop `wishlists` / `wishlist_items` (reverse migration `0004`).
2. Remove `routes/wishlist.ts` + mount line, `use-wishlist.tsx`,
   `wishlist-panel.tsx`, and the wishlist branch in `use-scanned-cards.tsx`.

---

## Item 37 — Local art cache + in-flight dedupe (server)

**Status:** implemented, uncommitted.

### Why

Art requests previously hit the image CDN every time (slow, and useless for a
local-only build). The sync already downloads every card's image; now that
work is reused as a disk cache.

### What changed

- `packages/server/src/lib/art-cache.ts` — SHA-256-keyed disk cache under
  `.cache/art` (image + content-type meta), a best-effort `saveArtToCache`,
  and `fetchImageWithCache` with in-flight dedupe (concurrent requests for the
  same URL share one upstream fetch).
- `routes/card.ts` image proxy now serves from the cache first.
- `lib/sync-job.ts` warms the cache for every image it downloads for
  embedding, so after a game sync its art is fully local and instant.

### Behavior notes

- Cache dir is `process.cwd()/.cache/art` (override with `ART_CACHE_DIR`).
- The bulk catalogs (Scryfall etc.) were already cached on disk; this extends
  that to individual card art.

### How to revert

1. Delete `lib/art-cache.ts`; restore the image proxy's direct fetch.
2. Remove the `saveArtToCache` call in `sync-job.ts`.

## Item 38 — Scan-aware sync pacing + Postgres RAM tuning (server + scripts)

**Status:** implemented, uncommitted.

### Why

A full-tilt sync saturates the DirectML GPU, and on Windows the desktop
compositor (DWM) shares that GPU — so the whole machine feels sluggish during
sync even though CPU sits at ~2 %. The scanner also needs the GPU for its own
per-scan embed, so a running sync can delay scans.

### What changed

- **`lib/scan-activity.ts` (new)** — `recordScan()` / `recentScanWithin(ms)`
  track when the last scan embed happened.
- **`routes/card.ts`** — calls `recordScan()` after each successfully
  vectorized scan.
- **`lib/sync-job.ts`** — pacing between fetch/embed batches:
  - `SYNC_FETCH_BATCH` / `SYNC_EMBED_BATCH` env vars (defaults 16 / 8) so the
    batch sizes are tunable without code edits.
  - `SYNC_PACE_SCAN_MS` (default 200) delay per batch while the scanner was
    used in the last 5 s; `SYNC_PACE_IDLE_MS` (default 10) otherwise. Idle
    cost is negligible; the machine stays responsive during a sync.
- **`scripts/local-db.mjs`** — Postgres now starts with
  `-c shared_buffers=1GB` (was the 128 MB default), so the card catalog +
  vector index stay resident in RAM. Applied on next Postgres start/restart
  (both `start` and the logon auto-start launcher).

### Behavior notes

- Sync is still one game at a time and fully resumable; the pacing only
  changes timing between batches.
- The GPU/memory “half free” numbers during sync are normal: SigLIP uses a
  small slice of VRAM; the 100 % is compute utilization, and the card
  *lookups* (pgvector search) run on CPU in Postgres, not the GPU.

### How to revert

1. Remove the `pace()` calls + env vars from `sync-job.ts` and the
   `recordScan()` call from `routes/card.ts`; delete `lib/scan-activity.ts`.
2. Drop `-c shared_buffers=1GB` from `scripts/local-db.mjs` (both places).

## Item 39 — Docs refresh + bootstrap rename (docs + scripts)

**Status:** implemented, uncommitted.

### Why

After items 11–13 removed hosted Neon, the file name
`packages/server/sql/local-neon-bootstrap.sql` was a misleading leftover for
anyone onboarding. The README (GitHub landing page) also still referenced a
Docker deployment and a feature list that predated bundle/chase/wishlist
mode, and the Arduino README still pointed at the old Logitech webcam.

### What changed

- **`packages/server/sql/local-neon-bootstrap.sql` → `local-bootstrap.sql`**
  (renamed; references updated in `README.md`, `.env.example`, `db/index.ts`,
  `db/schema.ts`, and the file's own header).
- **`README.md`** rewritten: current feature set (bundle/chase/wishlist, value
  binning, holo detection, bin status, export/duplicates/set-completeness,
  art cache), accurate stack versions, real step-by-step getting-started,
  removed the stale Docker/nginx deployment section, hardware + webcam now
  match the EMEET C60E + scan light.
- **`custom/README.md`** — status checklist replaced with a summary of the
  38 documented items.
- **`arduino/main/README.md`** — scan light (LED 5 / ch14) added to the
  channel summary; webcam section updated to the EMEET C60E.
- **`custom/SETUP.md`** — `/app/library` added to the page list.
- **`.env.example`** — sync pacing variables documented.

### How to revert

1. Rename `packages/server/sql/local-bootstrap.sql` back and restore the
   references.
2. Restore the previous README/docs from git.

## Item 40 — Dependency security pass (repo)

**Status:** implemented, uncommitted.

### Why

`pnpm audit` flagged 2 critical and 45 high-severity advisories. The criticals
were transitive through the vision stack (`@huggingface/transformers` →
`onnxruntime-web`/`onnxruntime-node` → `protobufjs`/`tar`), and several highs
were in our direct runtime deps (hono, @hono/node-server, drizzle-orm,
react-router-dom, vite).

### What changed

- **Bumped direct deps** — hono `^4.12.4` (4.12.34), `@hono/node-server`
  `^2.0.12` (2.x — 1.x is EOL for the serve-static advisory), drizzle-orm
  `^0.45.2`, react-router-dom `^7.18.2`, vite `^6.4.3`, turbo `^2.10.8`,
  shadcn `^4.16.1`.
- **pnpm overrides (root `package.json`)** for transitives with no patched
  release in their pinned line: `protobufjs >=7.6.1` (→8.7.1),
  `tar >=7.5.19` (→7.5.22), `sharp >=0.35.3` (libvips CVEs), `kysely
  >=0.28.17`.
- **Verified the vision path still works** after the sharp override — a live
  scan (image → sharp decode → SigLIP/DirectML embed → pgvector search)
  returned 200 on a fresh server process; the web build passes with
  react-router 7.18.

### Result

`pnpm audit`: **critical 2 → 0**; high 45 → 21, of which **0 are in runtime
paths** (the remaining highs are dev-tooling transitives via the `shadcn` CLI,
`tsup`, and ESLint — never shipped). One react-router advisory is flagged but
only affects RSC mode (server actions), which this SPA does not use; the fix
is v8-only.

### How to revert

1. Restore the three `package.json` files and `pnpm-lock.yaml` from git, then
   `pnpm install`.
2. Remove the `pnpm.overrides` block from root `package.json`.

## Item 41 — Fix theme toggles + bundle SKU/inventory (web + server)

**Status:** implemented, uncommitted.

### Why

Two things: (a) the Light/Dark/System theme toggles did nothing — `next-themes`
`useTheme()` was used but no `ThemeProvider` was mounted (the provider lived in
the auth-gated layout removed in item 13, so this has been broken since); (b) a
seller needs every completed bundle to be traceable — a SKU, the list of cards
that went into it, and a CSV record for disputes/claims.

### What changed

- **Theme** — `packages/web/src/main.tsx` now wraps the app in
  `<ThemeProvider attribute="class" defaultTheme="system" enableSystem>`;
  the CSS already had the class-based `dark` variant and `.dark` variables.
- **Bundle SKU** — `bundle_runs.sku` column (migration `0005_bundle_sku`)
  assigned at run start: `{ACRONYM}-{CARD_COUNT}-{SEQ}` (e.g. `MTG-40-001`)
  from the config's game + total target count + per-game run sequence.
  `bundle_configs.game_key` column records the game (picked in the bundle
  editor, defaulting to the active collection's game). Shared
  `GAME_ACRONYMS` / `gameAcronym()` in
  `packages/shared/src/constants/game-acronyms.constant.ts` (MTG/YGO/PKM/DIG/GUN,
  `TCG` fallback).
- **Bundle inventory** — new endpoints: `GET /bundles/runs` (all runs),
  `GET /bundles/run/:guid/cards` (card details grouped with qty),
  `GET /bundles/run/:guid/csv` (downloadable inventory CSV). The panel shows
  the SKU on the active run, a **Bundle inventory** list of past runs, a
  view-cards dialog, and an Export CSV button per run.
- Seeder now sets `game_key: "mtg"` on the default bundle.

### Behavior notes

- Existing runs/configs predating the columns show no SKU/game until a new
  run is started (configs can be edited to set a game).
- The CSV is the inventory record: SKU, config, game, date, card count, total
  value, then per-card rows (qty, name, set, rarity, price).

### How to revert

1. Drop migration `0005` (`bundle_runs.sku`, `bundle_configs.game_key`).
2. Remove the SKU/inventory endpoints + panel additions and the
   `ThemeProvider` wrap in `main.tsx`.

## Item 42 — Gundam card-data fix + backend production hardening (server)

**Status:** implemented, uncommitted.

### Why

(a) The Gundam sync adapter stored cards + embeddings but never populated
`card_data` (its `fetchCards` only kept id/name/set/image), so library,
detail hydration, and bundle CSV exports showed empty data for Gundam — the
only game with that gap. (b) The server had no health endpoint, logged into
the void (hidden window), returned no JSON for 404s/500s, and had no graceful
shutdown or fail-fast config check.

### What changed

- **Gundam** — `lib/gundam/sync.ts` now maps each row through
  `normalizeGundamCard()` so `card_data` is stored; re-running the sync
  backfilled all 1,816 existing rows (the sync's existing backfill path).
  DB now has full card_data for all five games.
- **`src/index.ts`** — production hardening:
  - `GET /api/health` — liveness + DB reachability (`SELECT 1`), returns
    `{ success, status, uptime, timestamp }` or 503.
  - `app.notFound` / `app.onError` — JSON 404 / 500 for every route (the web
    client always parses JSON).
  - Fail-fast `DATABASE_URL` check on boot with a clear message.
  - Graceful shutdown on SIGINT/SIGTERM (close DB pool, exit cleanly).
  - `uncaughtException` / `unhandledRejection` handlers that log then exit(1)
    so a crash is visible in the log.
- **`scripts/start-server.cmd`** — server output now appends to
  `C:\Mault Revised\mault\server.log` instead of vanishing.
- **`custom/PLAN.md`** — new “v2 machine” section: MG90S servo upgrade,
  interrupt-driven / comparator / encoder card detection options, and the
  ~1.5–2 s/card target.
- **`custom/TCGS.md`** — per-game sync completeness table updated.

### How to revert

1. Revert `lib/gundam/sync.ts` to the minimal mapping (rows keep null
   card_data).
2. Restore the previous `src/index.ts` and `scripts/start-server.cmd` from git.

## Item 43 — Hardware v2 production review doc (docs)

**Status:** implemented, uncommitted.

### Why

Goal is small-scale production: a faster, more reliable machine (not PLA, a
stable heavy base), and long-term concurrent multi-machine operation (3
machines + 3 cameras off one PC) instead of one bigger machine.

### What changed

- **`custom/HARDWARE_V2.md` (new)** — production review covering:
  - **Materials:** PLA → ASA/PETG per part (creep/heat/toughness table),
    heat-set brass inserts, connectorized modules, when injection molding wins.
  - **Stability/mass:** steel base plate (~4 kg), sorbothane feet, one rigid
    aluminum backplate spine, camera on the machine — the cheapest way to
    shorten the blind routing delays.
  - **Mechanism:** MG90S, brass bushings/bearings at pivots, steel pin through
    flappers, silicone pinch roller + hopper agitator + feeder encoder.
  - **Multi-machine:** `station_id` software plan (per-machine scans/bin
    status/bundle runs; shared card library + configs), USB/power/camera
    sizing for 3 stations, single-GPU embed queue math, and a throughput
    table (~50k cards/8-h shift on a 3-machine v2 farm).
  - **Market comparison:** vs TCGplayer's **Roca Sorter** (~$25k, 500 sort /
    725 sift per hr, 1,000-card batches) — our v1 already sorts ~2.4× faster
    on raw throughput and the 3× v2 farm ~12.6×, at 1/10 the cost. Roca's real
    value is inventory digitization, alphabetizing, sleeved-card handling,
    and unattended batches — logged as feature gaps to borrow, not speed gaps.
  - **Measurement gate:** the roadmap now orders *finish v1 software → build
    + tune the first machine → measure cards/hr, error rate, jams &
    double-feeds per 1,000 → cheap upgrades, re-measure → v2 → farm*, so
    every hardware dollar is justified by a measured number.
- `custom/README.md` + `custom/PLAN.md` — doc index updated to point at it.

### How to revert

1. Delete `custom/HARDWARE_V2.md` and revert the index links.

## Item 44 — Orientation-tolerant crop + digitize mode (web + shared)

**Status:** implemented, uncommitted.

### Why

Two scanner capabilities that move toward the v2/Roca-style workflow:
(a) cards fed upside-down (end-over-end) previously failed to match because
SigLIP embeddings are orientation-sensitive; (b) bulk-recording a library
(before pricing/listing) needed a “record everything, sort nothing” mode.

### What changed

- **Orientation-tolerant crop** — `autoOrientCard()` in
  `packages/web/src/features/scanner/lib/card-detection.ts`: after the fixed
  scan-region crop, a cheap downscaled grayscale pass compares the ink density
  of the top vs bottom bands (light name bar vs dense rules-text box — a
  layout shared by every supported TCG) and rotates the crop 180° when it is
  clearly flipped. Conservative threshold: ambiguous cards stay as-fed
  (a wrong flip would no-match, which is visible). Wired into the capture
  path in `use-card-scanner.ts` so foil detection and the upload both see an
  upright card.
- **Digitize mode** — `digitize` / `setDigitize` on the scanned-cards
  context; when on, `addCard` records the scan but bypasses bundle/chase/
  wishlist/bin rules entirely and routes to the catch-all bin (capacity
  check included) so the machine keeps moving. New `DigitizeModeToggle` in
  the scanner sidebar (all three layouts).
- **Sleeved capacity (shared)** — `CARD_THICKNESS_SLEEVED_MM = 0.7` and
  `computeBinCapacity(bin, thickness)` so the app's capacity model can switch
  to sleeved limits with one value (v2 sleeve-tolerant work).
- **Docs** — `custom/HARDWARE_V2.md` gained a “Sleeve tolerance” section
  (gaps, foil calibration on sleeves, capacity); `custom/TCGS.md` gained the
  TCGplayer integration investigation + roadmap; `custom/SETUP.md` documents
  both new scanner features. Alphabetizing is explicitly out of scope.

### How to revert

1. Remove the `autoOrientCard` call in `use-card-scanner.ts` and the
   function in `card-detection.ts`.
2. Remove the digitize branch in `use-scanned-cards.tsx`, the context
   fields, and `DigitizeModeToggle`.
3. Drop the sleeved constant (keep `computeBinCapacity` with its default).

## Item 45 — TCGplayer inventory CSV export (web)

**Status:** implemented, uncommitted.

### Why

Step 1 of the TCGplayer integration roadmap (`custom/TCGS.md`): the
no-API 80/20 win — export a scan/digitize session as a TCGplayer-compatible
inventory CSV, uploaded in the seller portal without any API access.

### What changed

- **`packages/web/src/features/cards/lib/tcgplayer-export.ts`** —
  `buildTcgplayerCsv()` / `downloadTcgplayerCsv()`: groups scanned cards by
  card id + foil variant, emits the community-standard inventory shape
  (`name, set_name, condition, quantity, purchase_price, list_price,
  tcgplayer_id`).
  - Condition defaults to **Near Mint** (operator edits before upload).
  - Foil scans get `(Foil)` appended to the name (TCGplayer's foil product
    naming) and use `prices.usd_foil` when available.
  - `list_price` from the card price; blank when the source has none.
  - `purchase_price` and `tcgplayer_id` are left blank (no cost tracking yet;
    IDs come with the API integration).
- **`card-grid.tsx`** — **TCG CSV** button next to Export CSV, exports all
  scanned cards.
- Verified output shape with a sample-data run (grouping, foil rows, foil
  pricing, blank prices all correct).

### How to revert

1. Remove the TCG CSV button + handler from `card-grid.tsx` and delete
   `tcgplayer-export.ts`.

## Item 46 — QoL quick wins + product strategy doc (web + docs)

**Status:** implemented, uncommitted.

### Why

Adoption-first thinking for v1: fix the trust/feedback gaps a home user hits
on day one, and capture the v1→v2 product strategy so the roadmap has a
thesis.

### What changed

- **Sounds** — `use-card-scanner.ts`: successful matches now play a short
  ascending chime; no-match plays a distinct low square tone. Previously the
  *same* ding played on no-match and matches were silent (inverted UX).
- **Undo last scan** — `use-scanned-cards.tsx` tracks the most recently
  committed scan (`lastScanIdRef`) and exposes `undoLastScan()` (removes the
  record; the physical card is moved by hand). **Undo last** button added to
  the card-grid toolbar.
- **`custom/PRODUCT.md` (new)** — v1 home vs v2 commercial positioning, the
  five adoption drivers (correctness, trust, easy setup, fun, no surprises),
  and a value-vs-effort feature backlog with status markers (many items
  already built; quick wins flagged for the next session).
- `custom/README.md` — doc index updated.

### How to revert

1. Restore the single ding in `use-card-scanner.ts` (or revert the file).
2. Remove `lastScanIdRef`/`undoLastScan` from `use-scanned-cards.tsx`,
   `types.ts`, and the toolbar button.
3. Delete `custom/PRODUCT.md` and revert the index link.

---

## Item 48 — Rebrand to DeckSift + custom license + credit restructure (repo)

**Status:** implemented, uncommitted.

### Why

DeckSift has grown into a distinct product built on MAULT, and the repo was
presenting it ambiguously: browser tab said MAULT, the app said "Magic Vault",
"Report an issue" pointed at the upstream repo, and the LICENSE named only the
original author. The v1→v2 plan also needs a licensing model that lets home
users build the machine for free while reserving commercial sales to the
DeckSift team.

### What changed

- **`LICENSE`** — new DeckSift License: copyright © 2026 4holdingdirectlimited.
  Personal/non-commercial use is free; commercial use (selling DeckSift or
  building it into a product) requires a license from the copyright holder.
  The MAULT-derived portions (original Fusion design, build photos, firmware
  base) remain MIT with the original Kenneth Bass notice included verbatim.
- **Product name** — all user-facing strings now say **DeckSift**: landing
  page (hero/nav/features/pipeline/cta/footer/open-source), build guide
  (nav/hero/footer), app sidebar nav, browser tab (`index.html` +
  `document-title-updater.tsx`), and Discord notification titles (server).
- **Credit restructure** — credit for the v1 machine's Fusion 3D design,
  build photos, and firmware base stays explicit and prominent (footers,
  `/build` guide, README Credits, `arduino/main` docs): "the sorter we built
  from" by dishwasher-detergent (MIT). The DeckSift work — software stack,
  firmware modifications, planned revised Bambu Lab print kit — is credited to
  4holdingdirectlimited.
- **"Report an issue"** — build guide footer/nav now point at
  `4holdingdirectlimited/DeckSift/issues` instead of the upstream repo.
- **Repo renamed** on GitHub from `mault` to **`DeckSift`**; the git
  `origin` remote and all fork-repo links now use the new URL.
- **README / custom docs** — rewritten intro, Credits, license summary, and
  PRODUCT.md positioning for the personal-free / commercial-by-license model.
- **Not changed (deliberately):** the `@magic-vault/*` package names, the
  local database name, the `C:\Mault Revised` path, and the upstream repo
  links for the 3D model files (those files genuinely live upstream).

### How to revert

1. Restore `LICENSE` to the upstream MIT text.
2. Replace the "DeckSift" strings with the previous name in the files above.
3. Point "Report an issue" back at `dishwasher-detergent/mault/issues/new`.
4. Revert README/custom-doc edits.

---

## Item 49 — Review queue, set-completeness toast, non-blocking firmware state machine + interrupt IR (web + firmware)

**Status:** implemented, uncommitted.

### Why

Closes the last big trust gap (low-confidence scans auto-routed without a human
check), makes set progress visible mid-run, and delivers the firmware roadmap's
two speed/robustness items: a non-blocking operation machine and interrupt-
driven card detection.

### What changed

**Review queue (web)**
- `packages/shared/src/interfaces/scanner.interface.ts` — `ScannerStatus` gains
  `"review"`.
- `packages/web/src/features/scanner/api/use-card-scanner.ts` — when the top
  match is low-confidence (`distance >= 0.18`) or has close alternatives, the
  scan pauses with `pendingReview` instead of auto-routing. `confirmReview()`
  sorts normally; `rejectReview()` routes the physical card to the catch-all
  via the no-match path. Toggle persisted in localStorage (default ON) and
  surfaced in the scanner menu.
- `packages/web/src/features/scanner/components/review-panel.tsx` (new) —
  overlay with the card image, name, confidence %, and Sort it / Skip buttons.
- `packages/web/src/features/scanner/components/card-scanner.tsx` +
  `scanner-menu.tsx` — panel wired in, “Review low-confidence” menu toggle.

**Set-completeness toast (web)**
- `packages/web/src/features/scanner/lib/set-progress.ts` (new) — counts unique
  cards owned per set and compares with the set's total in the synced library;
  toasts on milestones (first card, every 5th, completion) to avoid spam.
- `use-scanned-cards.tsx` — fires it whenever a new scan lands.

**Non-blocking firmware state machine + interrupt IR (firmware)**
- `arduino/main/main.ino` rebuilt: `runFeeder`/`routeCard`/test/clear are now
  phases of a `runMachine()` state machine driven from `loop()`, so serial is
  serviced mid-operation (`{"cancel":true}` aborts any phase; jam alerts abort
  immediately; commands mid-run get `{"error":"busy"}`; oversized lines are
  reported). The whole-operation watchdog replaces the old command deadline.
- Module-1 IR is interrupt-driven (`attachInterrupt` + volatile flag); the
  feeder runs continuously and stops the instant the beam is crossed — the
  old pulse/pause feeding cycle is gone.
- Command protocol and replies are unchanged (`status`/`bin`/`detected`/
  `empty`/`error` with id echo), so the web app needs no protocol changes.

### Behavior notes

- Review queue is on by default; disable it from the scanner menu for
  unattended runs (e.g. digitize/bulk sessions).
- The feeder now ignores `pulseDuration`/`pauseDuration` (continuous feed);
  `settleDuration` still controls the last-card push.
- Firmware compiled: 79,240 bytes (30%) flash, 6,316 bytes (19%) RAM.

### How to revert

1. Remove the `"review"` status + review-queue logic and the panel/menu toggle.
2. Remove `set-progress.ts` and its effect in `use-scanned-cards.tsx`.
3. Restore the previous blocking firmware (`git` history of `main.ino`).

---

## Item 47 — Six adoption features: CSV import, condition, badge, shortcuts, backup script, first-run checklist (server + web + scripts)

**Status:** implemented, uncommitted.

### Why

Closes out the v1 adoption backlog from `custom/PRODUCT.md`: import an existing
collection (the strongest hook for chase/set-completeness), per-scan grading for
TCGplayer listings, instant trust signals on every card, keyboard control, a
one-command safety net, and a guided first-run path.

### What changed

**Collection CSV import (server + web)**
- `packages/server/src/routes/collections.ts` — new `POST /api/collections/:guid/import`
  (multipart `file`). Parses ManaBox/TCGplayer/Delver-style CSVs (case-insensitive
  header aliases: Name, Set/Set Name, Collector Number, Rarity, Foil, Condition,
  Qty, Price; RFC-4180 quoting). Rows are matched fully locally against the
  synced `cards` table by name (ILIKE, escaped) plus set code/name and collector
  number when present; `Qty` inserts one row per copy. Imports are inserted as
  `ScannedCard` rows (`binNumber` null, `distance` 0) and announced via
  `card_added` session events. Returns `{ success, count, errors }` where errors
  are per-row (line number + reason).
- `packages/web/src/features/collections/api/collections.ts` —
  `importCollectionCards(guid, formData)` (multipart via `apiPostForm`).
- `packages/web/src/app/routes/app/collections.tsx` — per-collection **Import
  CSV** button + dialog (file picker, format help, result toast with unmatched
  row preview).

**Condition field (server was done; frontend now complete)**
- `packages/web/src/features/collections/api/collections.ts` —
  `setCollectionCardCondition(guid, scanId, condition)` (PUT `{ condition }`).
- `packages/web/src/features/scanner/api/use-scanned-cards.tsx` + `types.ts` —
  `setCondition(scanId, condition?)` in the context.
- `packages/web/src/features/cards/components/card-detail-panel.tsx` — condition
  Select (Near Mint / Lightly Played / Moderately Played / Heavily Played /
  Damaged / Not graded) next to the Foil toggle.
- `packages/web/src/features/cards/lib/tcgplayer-export.ts` — TCG CSV now groups
  by card + foil + **condition** and emits each scan's condition (defaults
  "Near Mint").

**Match confidence badge**
- `packages/web/src/features/cards/components/scanned-card-item.tsx` — distance
  badge is now a colored dot + compact %: green < 0.15, amber < 0.25, red
  ≥ 0.25; imports/manual adds (no distance) show a neutral "—" instead of a
  misleading "0.00%".

**Keyboard shortcuts**
- `packages/web/src/features/scanner/api/use-scan-shortcuts.ts` (new) — Space =
  pause/resume, S = force scan, Z = undo last scan; ignored in inputs/textarea
  and with modifier keys. Mounted in the scanner route (`app/index.tsx`).

**Backup/restore script**
- `scripts/backup-db.mjs` (new) — `node scripts/backup-db.mjs backup [dir]`
  (pg_dump --clean --if-exists to `.local/backups/mault-<timestamp>.sql`),
  `list`, and `restore <file>` (psql restore with a bootstrap re-run hint).

**First-run checklist**
- `packages/web/src/features/setup/components/first-run-checklist.tsx` (new) —
  live checklist in the scanner sidebar: camera → Arduino → sync a game →
  calibrate servos → first scan; links to Admin / Calibrate / Build guide.

### Behavior notes

- CSV import never touches the network — it matches against the synced library
  only, so the game must be synced first (unmatched rows are reported, not
  silently dropped).
- `condition` is optional everywhere; blank grades stay "Near Mint" on TCG
  export.
- `guid` is a Postgres UUID — imported scan ids are plain `randomUUID()`s.

### How to revert

1. Remove the `/import` route + CSV helpers from `collections.ts`, and the
   import button/dialog from the collections page.
2. Drop `setCondition` from the provider/context type, the panel Select, and
   the TCG export condition grouping.
3. Revert the badge change in `scanned-card-item.tsx`; delete
   `use-scan-shortcuts.ts` and its usage; delete `scripts/backup-db.mjs`;
   delete the first-run checklist component and its sidebar mount.

---

## Item 50 — Integrate useful upstream additions (server + web)

**Status:** implemented, committed (this commit).

### Why

Upstream (dishwasher-detergent/mault) advanced ~16 commits past our fork. We
reviewed every diff and pulled in the changes that fit our local-only, no-auth,
DeckSift-branded tree — the rest was cosmetic (icon swaps), not portable
(auth/Neon), or upstream's own design files (3D models). The wins below
improve response time during scanning, fix raw-value select labels, and round
out the build docs.

### What changed

- **Server: generic adapter TTL cache** — new
  `packages/server/src/lib/card-search/cache.ts` (`withCache` wrapper with
  TTL + in-flight dedupe) applied to all five game adapters in `resolve.ts`
  (mtg, gundam, pokemon, yugioh, digimon). Search results now cache for
  15 min and concurrent identical lookups share one upstream request.
- **Web: "Min. match" filter** — `minMatchPercent` added to `CardFilters`
  (all three `EMPTY_FILTERS`), a new `components/ui/slider.tsx`, and a
  Min. match slider in the card-filter popover that hides low-confidence
  matches (`(1 - distance) * 100 >= threshold`).
- **Web: grid performance** — card grid now paginates (96/page) and
  `framer-motion`/`AnimatePresence` was removed from the card grid, card
  item, and monitor grid. This was the main render bottleneck while
  scanning with hundreds of cards (each scan re-triggered layout
  animation across the whole grid). Newest-scan flash (`isNew`/
  `newestScanId`) removed with it; scan feedback stays via stats + review
  queue.
- **Web: game-switch alert** — new `GameSwitchAlert` toast (amber,
  dismissible) after switching collection games, reminding to re-adjust the
  feeder tube wall; mounted in all three scanner layouts.
- **Web: select label fixes** — `SelectValue` now renders the human label
  (not the raw value) for condition field/operator/value selects, the
  collection-switcher game select, and the collections page game select.
- **Firmware/scan tuning:** `CARD_SETTLE_DELAY_MS` 300 → 500 (fewer
  mid-slide/blurred captures).
- **Docs:** "Flash the firmware" build phase moved earlier (before servo
  mounting), IR sensor short-throw calibration note added, and a full
  wiring diagram image added to the Build → Wiring page.

### Behavior notes

- The upstream global `Toaster` removal was **not** taken — we mount sonner's
  `<Toaster />` exactly once and rely on it for toasts.
- `AppLoadingGate` (full-screen splash) was **not** taken — our local,
  single-org app loads fast and already has inline skeletons.
- Pagination resets to page 0 on search/filter/sort/collection changes.

### How to revert

1. Revert `resolve.ts` to unwrapped adapters and delete `cache.ts`.
2. Remove `minMatchPercent` from `CardFilters` + the three `EMPTY_FILTERS`,
   the filter-sort block, the popover slider, and delete `slider.tsx`.
3. Restore `isNew`/`newestScanId`/`AnimatePresence` in `card-grid.tsx`,
   `scanned-card-item.tsx`, `monitor.tsx` if the animation is wanted back.
4. Delete `GameSwitchAlert` and its three mounts; set
   `CARD_SETTLE_DELAY_MS` back to 300.
5. Remove the SelectValue children in `condition-row.tsx`,
   `collection-switcher.tsx`, `collections.tsx`.
6. Move the firmware phase back in `assembly.tsx`, drop the IR note, and
   remove the wiring-diagram section + image from `wiring.tsx`.

---

## Item 51 — Configurable match thresholds + per-game alert dismissal (web)

**Status:** implemented, committed (this commit).

### Why

Item 50 brought upstream's view-only "Min. match" filter. The review queue
had the same concept hardcoded (`REVIEW_DISTANCE = 0.18`, i.e. pause below
82%), but different games score matches differently and a fixed threshold
mis-fires on some TCGs. Making the runtime thresholds adjustable — and adding
an auto-reject floor — turns the filter concept into automation.

### What changed

- **Review threshold slider** — Scanner menu → Scanner → "Review below %"
  replaces the hardcoded 82% pause point. Persisted in localStorage
  (`reviewMatchPercent`, default 82). Close-alternative matches still always
  pause.
- **Auto-reject floor slider** — "Auto-reject below %" (default 0 = off):
  cards below the floor are routed straight to the catch-all bin without
  pausing, keeping the line moving during unattended bundle runs. A toast
  reports each auto-rejection. Persisted in localStorage
  (`autoRejectMatchPercent`).
- **Per-game alert dismissal** — the game-switch feeder-tube alert remembers
  dismissed games (localStorage) so it only reappears when switching to a
  game you haven't dismissed.
- **Tailwind v4 lint fix** — `bg-gradient-to-br` → `bg-linear-to-br` (4 files)
  to clear the remaining Zed diagnostic.

### Behavior notes

- Auto-rejected cards are never added to the collection and don't set the
  duplicate guard, so a re-feed of the same card scans normally.
- Both sliders live in the Scanner submenu next to "Review low-confidence"
  and use the same drag pattern as the camera Zoom slider.

### How to revert

1. Restore the hardcoded `REVIEW_DISTANCE` check in `use-card-scanner.ts`
   and remove the two persisted settings + auto-reject branch.
2. Remove the two sliders from `scanner-menu.tsx` and their props through
   `card-scanner.tsx`.
3. Revert `game-switch-alert.tsx` to the always-show dismissal; restore
   `bg-gradient-to-br` if wanted.

---

## Item 52 — Scan-rate telemetry, per-game thresholds, monitor pagination, feeder retry (web)

**Status:** implemented, committed (this commit).

### Why

No-new-hardware speed/reliability pass. The machine isn't assembled yet, so
this batch is about making tuning measurable, keeping each TCG's match
thresholds independent, and removing two rough edges (monitor grid rendering
every card; a single feeder hiccup pausing the whole line).
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

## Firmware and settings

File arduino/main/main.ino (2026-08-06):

#include <ArduinoJson.h>
#include <Adafruit_PWMServoDriver.h>
#include "board-config.h"  // board abstraction: EEPROM, I2C pins, IR pins, interrupts

// Wi-Fi / WebSocket / OTA transport — ESP32 only; other boards compile
// without it (guarded so the sketch stays universal).
#if defined(ARDUINO_ARCH_ESP32)
#include <WiFi.h>
#include <WebSocketsServer.h>
#include <ArduinoOTA.h>
#include <ESPmDNS.h>
#endif

Adafruit_PWMServoDriver pwm = Adafruit_PWMServoDriver();

// PWM channel layout (PCA9685):
//   ch0    = LED 1 — scan light (angled holo-detection light, toggled by the
//            web app for two-frame foil scans)
//   ch1    = LED 2 — green “operating” indicator
//   ch2    = LED 3 — red “machine fault” indicator (jam / timeout)
//   ch3    = LED 4 — orange “software/comms fault” indicator
//   ch4-6   = Module 1 (bottom, paddle, pusher)
//   ch7-9   = Module 2
//   ch10-12 = Module 3
//   ch13    = Feeder (360° continuous rotation servo)
#define NUM_MODULES 3
#define MODULE_CHANNEL_OFFSET 4
#define FEEDER_CHANNEL 13

// Status LEDs (1-indexed). LED 1 is the scan light; 2-4 are status lamps the
// firmware drives itself (and the web app mirrors in the UI).
#define LED_SCAN   1
#define LED_GREEN  2
#define LED_RED    3
#define LED_ORANGE 4

// IR sensors (active-LOW: pin reads LOW when a card is present). Pin numbers
// live in board-config.h (same defaults across boards, overridable per build).
#define IR_TIMEOUT_MS  3000  // max ms to wait for a card before aborting

// Any module where a card sits at the gate continuously for this long with no
// routing command in progress (e.g. the app never sent a bin command) is
// reported as a jam. Only checked while idle (runMachine()).
#define JAM_TIMEOUT_MS 20000

// Declared here (before any function) because the Arduino builder hoists
// auto-generated function prototypes to the top of the file, above any type
// defined later — if these enums were declared next to the operation machine
// instead, the hoisted prototypes would precede them and fail to compile
// ("OpKind was not declared in this scope").
enum OpKind { OP_NONE, OP_ROUTE, OP_FEED, OP_TEST, OP_CLEAR };

enum Phase {
  PH_NONE,
  PH_FEED_RUN,     // feeder on; exit on module-1 IR edge or duration timeout
  PH_FEED_SETTLE,  // feeder on for settleDuration (last-card push into module 1)
  PH_WAIT_SENSOR,  // wait for a card at op.waitModule (IR_TIMEOUT_MS)
  PH_CARD_ENTER,   // DELAY_CARD_ENTER after the sensor sees the card
  PH_PADDLE,       // paddle open on op.waitModule (DELAY_PADDLE)
  PH_PUSH,         // pusher to side on op.waitModule (DELAY_PUSH)
  PH_NEUTRAL,      // all servos neutral + 200ms
  PH_HOLD,         // generic timed hold (op.holdMs), then neutral
  PH_TEST_OPEN,    // open bottoms + paddles (DELAY_PUSH)
  PH_TEST_LEFT,    // pushers left (DELAY_PUSH)
  PH_TEST_RIGHT,   // pushers right (DELAY_PUSH)
  PH_TEST_FEED,    // feeder on (500ms)
  PH_TEST_LED_ON,  // LED op.ledIndex on (150ms)
  PH_TEST_LED_OFF, // LED op.ledIndex off (100ms)
  PH_CLEAR_OPEN,   // all bottoms open (DELAY_PUSH)
};

void setLed(int led, bool on) {
  pwm.setPin(led - 1, on ? 4095 : 0);
}

int irPin(int module) {
  if (module == 1) return IR_PIN_MODULE1;
  if (module == 2) return IR_PIN_MODULE2;
  return IR_PIN_MODULE3;
}

bool hopperHasCards() {
  return digitalRead(IR_PIN_HOPPER) == LOW;
}

// ─── Interrupt-driven module-1 card detection ────────────────────────────────
// The feeder stops the instant the beam is crossed instead of waiting for a
// poll — this is what lets the motor run continuously (no pulse/pause cycling).
volatile bool g_m1CardSeen = false;

void onModule1IR() {
  if (digitalRead(IR_PIN_MODULE1) == LOW) g_m1CardSeen = true;
}

// ─── Non-blocking operation machine ──────────────────────────────────────────
// Every mechanical operation (feed, route, test, clear) is a state machine run
// from loop(), so serial stays responsive mid-operation: {"cancel":true} aborts
// any phase, jam alerts abort immediately, and new commands while busy get a
// clean {"error":"busy"} instead of being swallowed by a blocking delay().

struct OpState {
  OpKind kind;
  Phase phase;
  int bin;         // OP_ROUTE target bin (1-7)
  int waitModule;  // module whose IR sensor we're waiting for
  bool pushLeft;
  unsigned long holdMs;
  int ledIndex;
  unsigned long phaseStart;
  unsigned long deadline;  // whole-operation watchdog
  int replyId;             // command id to echo when the op completes
  bool hasReplyId;
};

OpState op;               // zero-initialized → kind = OP_NONE
bool cancelRequested = false;

// Queued feed (pipelining): the web requests the next card while a route is
// still running. We hold the request (no reply yet) until the route finishes,
// then start the feed and reply with the ORIGINAL command id — so the web's
// waiter only resolves when the card actually arrives at module 1.
bool pendingFeed = false;
int pendingFeedId = 0;
bool pendingFeedHasId = false;

// Any module where a card sits at the gate continuously for this long with no
// routing command in progress (e.g. the app never sent a bin command) is
// reported as a jam. Only checked while idle — runMachine() services it.
unsigned long modulePresentSince[NUM_MODULES + 1] = {0, 0, 0, 0};
bool moduleJamAlerted[NUM_MODULES + 1] = {false, false, false, false};

// New jam alert during an operation sets this flag so the active command
// aborts to neutral instead of driving servos into a jammed mechanism.
bool jamAbortRequested = false;

struct ModuleConfig {
  int bottomClosed, bottomOpen;
  int paddleClosed, paddleOpen;
  int pusherLeft, pusherNeutral, pusherRight;
};

ModuleConfig moduleConfig[NUM_MODULES] = {
  {300, 310, 300, 310, 295, 300, 305},
  {300, 310, 300, 310, 295, 300, 305},
  {300, 310, 300, 310, 295, 300, 305},
};

struct FeederConfig {
  int speed;          // PWM pulse for forward motion
  int duration;       // overall timeout (ms) — max total time before giving up
  int pulseDuration;  // kept for config compatibility (0 = continuous feed)
  int pauseDuration;  // kept for config compatibility
  int settleDuration; // ms to keep feeding after the IR first sees the card, so it
                       // travels all the way into the module 1 mechanism instead of
                       // stopping right at the sensor's beam
};

FeederConfig feederConfig = {315, 3000, 0, 50, 150};

// Routing delays (ms) — runtime-tunable via {"setTimingConfig": ...} and
// persisted to EEPROM with saveConfig, so commissioning tunes them from the
// browser without re-flashing. Defaults match the old compile-time constants.
struct TimingConfig {
  int cardEnterMs;  // time for card to settle after target bottom opens
  int paddleMs;     // time for paddle to engage
  int pushMs;       // time for pusher to complete its stroke
};
TimingConfig timingConfig = {300, 300, 600};

// ─── Calibration persistence (EEPROM) ───────────────────────────────────────
// Module/feeder config is persisted so a reboot (e.g. a power blip mid-run)
// restores the tuned values instead of silently reverting to stock pulses.
// The magic + version guard detects stale data from older firmware or a
// hardware change (e.g. servo swap) and falls back to factory defaults.
#define CONFIG_MAGIC       0x4D56  // "MV"
#define CONFIG_VERSION     2
#define CONFIG_EEPROM_ADDR 0

struct PersistedCalibration {
  uint16_t magic;
  uint8_t version;
  ModuleConfig modules[NUM_MODULES];
  FeederConfig feeder;
  TimingConfig timing;
};

// Factory defaults — keep in sync with the moduleConfig/feederConfig
// initializers above; resetConfig restores these.
void setFactoryDefaults() {
  // Small-travel safe defaults (borrowed from upstream's fix): pulses are all
  // within a few µs of each other so a freshly-flashed board barely moves its
  // servos — it cannot over-travel and strip a gear before calibration.
  ModuleConfig factoryModules[NUM_MODULES] = {
    {300, 310, 300, 310, 295, 300, 305},
    {300, 310, 300, 310, 295, 300, 305},
    {300, 310, 300, 310, 295, 300, 305},
  };
  memcpy(moduleConfig, factoryModules, sizeof(moduleConfig));
  feederConfig.speed = 315;
  feederConfig.duration = 3000;
  feederConfig.pulseDuration = 0;
  feederConfig.pauseDuration = 50;
  feederConfig.settleDuration = 150;
  timingConfig.cardEnterMs = 300;
  timingConfig.paddleMs = 300;
  timingConfig.pushMs = 600;
}

void loadCalibration() {
  PersistedCalibration stored;
  EEPROM.get(CONFIG_EEPROM_ADDR, stored);
  if (stored.magic == CONFIG_MAGIC && stored.version == CONFIG_VERSION) {
    memcpy(moduleConfig, stored.modules, sizeof(moduleConfig));
    feederConfig = stored.feeder;
    timingConfig = stored.timing;
  }
}

void saveCalibration() {
  PersistedCalibration data;
  data.magic = CONFIG_MAGIC;
  data.version = CONFIG_VERSION;
  memcpy(data.modules, moduleConfig, sizeof(moduleConfig));
  data.feeder = feederConfig;
  data.timing = timingConfig;
  EEPROM.put(CONFIG_EEPROM_ADDR, data);
  BOARD_EEPROM_COMMIT();  // flash-emulated EEPROM (ESP32/RP2040) needs commit()
}

// Routing delays are now runtime-tunable (timingConfig above, persisted with
// saveConfig) instead of compile-time #defines.

// Fixed-size serial line buffer — avoids String heap fragmentation on long
// sessions. Oversized lines are discarded cleanly.
#define INPUT_BUFFER_MAX 256
char inputBuffer[INPUT_BUFFER_MAX + 1];
int inputBufferLen = 0;

// ─── Wi-Fi transport (ESP32 only) ───────────────────────────────────────────
// Optional and additive: boards without Wi-Fi (Uno R4, Pico, STM32) compile
// without it. On ESP32 the firmware joins your LAN so the browser can talk to
// it over WebSockets and the Arduino IDE can push OTA updates over the
// network — USB Web Serial keeps working exactly as before.
#if defined(ARDUINO_ARCH_ESP32)

#define WIFI_HOSTNAME          "decksift-board"  // decksift-board.local; change per machine for multi-rig setups
#define WIFI_WS_PORT           81                // ws://decksift-board.local:81
#define WIFI_EEPROM_ADDR       128               // separate EEPROM block from calibration (addr 0)
#define WIFI_MAGIC             0x4457            // "DW"
#define WIFI_VERSION           1
#define WIFI_RECONNECT_MS      10000             // retry a lost link every 10 s
#define WIFI_CONNECT_TIMEOUT_MS 10000            // bounded connect wait at boot

struct PersistedWifi {
  uint16_t magic;
  uint8_t version;
  char ssid[33];
  char password[65];
};

WebSocketsServer webSocket(WIFI_WS_PORT);
bool wsClientConnected = false;
bool wifiEnabled = false;
bool wifiConnected = false;
bool mdnsStarted = false;
bool otaStarted = false;
char wifiSsid[33] = "";
char wifiPassword[65] = "";
char wifiIp[16] = "";
unsigned long lastWifiReconnectMs = 0;

// Every line the firmware emits (replies, boot "ready", async jam alerts)
// goes to USB serial AND is broadcast to any WebSocket client. Both transports
// speak the same id-correlated protocol, so the web app's serial layer cannot
// tell the difference — and a Serial Monitor can stay open beside a Wi-Fi
// session without confusing anything.
void transportSend(const char* line) {
  Serial.println(line);
  if (wsClientConnected) webSocket.broadcastTXT(line);
}

void loadWifi() {
  PersistedWifi stored;
  EEPROM.get(WIFI_EEPROM_ADDR, stored);
  if (stored.magic == WIFI_MAGIC && stored.version == WIFI_VERSION) {
    strncpy(wifiSsid, stored.ssid, sizeof(wifiSsid) - 1);
    strncpy(wifiPassword, stored.password, sizeof(wifiPassword) - 1);
  }
}

void saveWifi() {
  PersistedWifi data;
  data.magic = WIFI_MAGIC;
  data.version = WIFI_VERSION;
  strncpy(data.ssid, wifiSsid, sizeof(data.ssid) - 1);
  strncpy(data.password, wifiPassword, sizeof(data.password) - 1);
  data.ssid[sizeof(data.ssid) - 1] = '\0';
  data.password[sizeof(data.password) - 1] = '\0';
  EEPROM.put(WIFI_EEPROM_ADDR, data);
  BOARD_EEPROM_COMMIT();  // flash-emulated EEPROM (ESP32) needs commit()
}

void connectWifi() {
  if (wifiSsid[0] == '\0') return;
  wifiEnabled = true;
  WiFi.mode(WIFI_STA);
  WiFi.setHostname(WIFI_HOSTNAME);
  WiFi.begin(wifiSsid, wifiPassword);
}

// Shared "we just got an IP" startup: record the address, start mDNS + OTA
// once, and announce the address. Called from checkWifi() on every first
// connect AND from setup()'s bounded wait, so a boot-time connection gets the
// full stack too — the web app auto-fills the Wi-Fi IP from this announce.
void onWifiConnected() {
  wifiConnected = true;
  String ip = WiFi.localIP().toString();
  strncpy(wifiIp, ip.c_str(), sizeof(wifiIp) - 1);
  wifiIp[sizeof(wifiIp) - 1] = '\0';
  if (!otaStarted) {
    // Flash the orange comms LED during an OTA update so it's obvious a
    // network flash is in progress.
    ArduinoOTA.onStart([]() { setLed(LED_ORANGE, true); });
    ArduinoOTA.onEnd([]() { setLed(LED_ORANGE, false); });
    ArduinoOTA.onError([](ota_error_t) { setLed(LED_ORANGE, false); });
    ArduinoOTA.begin();
    otaStarted = true;
  }
  if (!mdnsStarted) {
    // Start mDNS LAST: on this core ArduinoOTA.begin() re-initializes mDNS
    // with an esp32-<mac> hostname, which would otherwise clobber the
    // decksift-board.local name registered here. OTA's _arduino._tcp service
    // stays; only the hostname needs re-asserting.
    MDNS.begin(WIFI_HOSTNAME);
    MDNS.addService("ws", "tcp", WIFI_WS_PORT);
    mdnsStarted = true;
  }
  JsonDocument res;
  res["status"] = "wifi";
  res["ip"] = wifiIp;
  String line;
  serializeJson(res, line);
  transportSend(line.c_str());
}

// Called from loop(): tracks connect state, announces the assigned IP once
// ({"status":"wifi","ip":"..."} — the web app auto-fills it), and retries
// a lost link without blocking the machine. mDNS + OTA are started lazily on
// the first successful connection so credentials saved after boot (the normal
// first-run flow) get the full stack too.
void checkWifi() {
  if (!wifiEnabled) return;
  if (WiFi.status() == WL_CONNECTED) {
    if (!wifiConnected) onWifiConnected();
    return;
  }
  if (wifiConnected) {
    wifiConnected = false;
    wifiIp[0] = '\0';
  }
  if (millis() - lastWifiReconnectMs > WIFI_RECONNECT_MS) {
    lastWifiReconnectMs = millis();
    WiFi.disconnect();
    WiFi.begin(wifiSsid, wifiPassword);
  }
}

// WebSocket client events. On connect we mirror the boot handshake so the web
// app's connect flow (wait for "ready" → protocol check → mechanical test)
// works identically over USB and Wi-Fi.
void onWsEvent(uint8_t num, WStype_t type, uint8_t* payload, size_t length) {
  switch (type) {
    case WStype_CONNECTED:
      wsClientConnected = true;
      webSocket.sendTXT(num, "{\"status\":\"ready\",\"proto\":2}");
      break;
    case WStype_TEXT:
      if (payload != nullptr && length > 0) {
        handleCommand((char*)payload);  // same JSON protocol as serial
      }
      break;
    case WStype_DISCONNECTED:
      wsClientConnected = false;
      break;
    default:
      break;
  }
}
#else
// Boards without Wi-Fi: every line goes only to USB serial.
void transportSend(const char* line) {
  Serial.println(line);
}
#endif

// ─── Request/response correlation. A command may carry an optional numeric "id";
// every reply to that command then echoes it, so the web app can match
// responses to requests even while the firmware emits asynchronous messages
// (e.g. the jam alert) in between. Messages that are NOT replies to a command
// (boot "ready", jam alerts) intentionally never carry an id.
int g_cmdId = 0;
bool g_hasCmdId = false;

void replyJson(JsonDocument& res) {
  if (g_hasCmdId) res["id"] = g_cmdId;
  String line;
  serializeJson(res, line);
  transportSend(line.c_str());
}

void replyLiteral(const char* json) {
  if (!g_hasCmdId) {
    transportSend(json);
    return;
  }
  JsonDocument res;
  deserializeJson(res, json);
  res["id"] = g_cmdId;
  String line;
  serializeJson(res, line);
  transportSend(line.c_str());
}

int getChannel(int module, int servoOffset) {
  return MODULE_CHANNEL_OFFSET + (module - 1) * 3 + servoOffset;
}

void setServoPosition(int channel, int pulse) {
  pwm.setPWM(channel, 0, constrain(pulse, 120, 490));
}

void setModuleNeutral(int module) {
  ModuleConfig& c = moduleConfig[module - 1];
  setServoPosition(getChannel(module, 0), c.bottomClosed);
  setServoPosition(getChannel(module, 1), c.paddleClosed);
  setServoPosition(getChannel(module, 2), c.pusherNeutral);
}

void setAllNeutral() {
  for (int m = 1; m <= NUM_MODULES; m++) setModuleNeutral(m);
  stopFeeder();
}

void stopFeeder() {
  pwm.setPin(FEEDER_CHANNEL, 0);  // cut PWM signal entirely to stop 360° servo
}

// Idle-time jam watch — one entry per module index (1..NUM_MODULES; see
// checkModuleJams()).
void checkModuleJams() {
  for (int m = 1; m <= NUM_MODULES; m++) {
    bool present = digitalRead(irPin(m)) == LOW;
    if (!present) {
      modulePresentSince[m] = 0;
      moduleJamAlerted[m] = false;
      continue;
    }
    if (modulePresentSince[m] == 0) {
      modulePresentSince[m] = millis();
      continue;
    }
    if (!moduleJamAlerted[m] && millis() - modulePresentSince[m] > JAM_TIMEOUT_MS) {
      moduleJamAlerted[m] = true;
      jamAbortRequested = true;
      setLed(LED_RED, true);
      JsonDocument res;
      res["error"] = "jam";
      res["module"] = m;
      String line;
      serializeJson(res, line);
      transportSend(line.c_str());  // async — deliberately no command id
    }
  }
}

int getPositionPulse(int module, int servoOffset, const char* position) {
  ModuleConfig& c = moduleConfig[module - 1];
  if (servoOffset == 0) {
    if (strcmp(position, "open") == 0)   return c.bottomOpen;
    return c.bottomClosed;
  }
  if (servoOffset == 1) {
    if (strcmp(position, "open") == 0)   return c.paddleOpen;
    return c.paddleClosed;
  }
  if (servoOffset == 2) {
    if (strcmp(position, "left") == 0)   return c.pusherLeft;
    if (strcmp(position, "right") == 0)  return c.pusherRight;
    return c.pusherNeutral;
  }
  return -1;
}

int getServoOffset(const char* servo) {
  if (strcmp(servo, "bottom") == 0) return 0;
  if (strcmp(servo, "paddle") == 0) return 1;
  if (strcmp(servo, "pusher") == 0) return 2;
  return -1;
}

// ─── Operation machine: start helpers ────────────────────────────────────────

void clearOp() {
  op.kind = OP_NONE;
  op.phase = PH_NONE;
  setLed(LED_GREEN, false);
}

void beginOp(OpKind kind, unsigned long budgetMs) {
  op.kind = kind;
  op.phase = PH_NONE;
  op.bin = 0;
  op.waitModule = 0;
  op.pushLeft = false;
  op.holdMs = 0;
  op.ledIndex = 1;
  op.deadline = millis() + budgetMs;
  op.replyId = g_cmdId;
  op.hasReplyId = g_hasCmdId;
  cancelRequested = false;
  jamAbortRequested = false;
  setLed(LED_GREEN, true);   // an operation is running
  setLed(LED_RED, false);    // a fresh command clears the fault lamp
}

// Reply to the command that started the op (not the most recent command — a
// ping could have arrived mid-operation).
void replyOpJson(JsonDocument& res) {
  if (op.hasReplyId) res["id"] = op.replyId;
  String line;
  serializeJson(res, line);
  transportSend(line.c_str());
}

void finishOpOkRouted() {
  JsonDocument res;
  res["status"] = "routed";
  res["bin"] = op.bin;
  replyOpJson(res);
  clearOp();
}

void finishFeedDetected() {
  JsonDocument res;
  res["status"] = "ok";
  res["detected"] = true;
  res["empty"] = false;
  replyOpJson(res);
  clearOp();
}

void finishFeedEmpty() {
  JsonDocument res;
  res["error"] = "empty: feeder hopper is out of cards";
  res["empty"] = true;
  replyOpJson(res);
  clearOp();
}

void finishOpError(const char* msg) {
  setLed(LED_RED, true);
  JsonDocument res;
  res["error"] = msg;
  replyOpJson(res);
  clearOp();
}

void finishOpAborted(const char* msg) {
  JsonDocument res;
  res["error"] = msg;
  res["aborted"] = true;
  replyOpJson(res);
  clearOp();
}

void finishTestComplete() {
  JsonDocument res;
  res["status"] = "test_complete";
  replyOpJson(res);
  clearOp();
}

void finishCleared() {
  JsonDocument res;
  res["status"] = "cleared";
  replyOpJson(res);
  clearOp();
}

// Branch after the card has been fed into module 1 — per-bin routing plan.
void afterFeedDone() {
  if (op.kind == OP_FEED) {
    finishFeedDetected();
    return;
  }
  int bin = op.bin;
  if (bin == 7) {
    // Catch-all: open every bottom so the card drops to the catch-all position.
    for (int m = 1; m <= NUM_MODULES; m++) {
      setServoPosition(getChannel(m, 0), moduleConfig[m - 1].bottomOpen);
    }
    op.phase = PH_HOLD;
    op.holdMs = timingConfig.pushMs;
  } else if (bin == 1 || bin == 2) {
    // Module 1: open paddle, then push.
    op.pushLeft = (bin == 1);
    op.waitModule = 1;
    op.phase = PH_PADDLE;
    setServoPosition(getChannel(1, 1), moduleConfig[0].paddleOpen);
  } else {
    // Bins 3-6: open module 1 bottom and await the card at the next module.
    op.pushLeft = (bin == 3 || bin == 5);
    op.waitModule = 2;
    op.phase = PH_WAIT_SENSOR;
    setServoPosition(getChannel(1, 0), moduleConfig[0].bottomOpen);
  }
  op.phaseStart = millis();
}
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
void loop() {
  // Serial stays responsive during operations: the machine below runs on its
  // own timers/sensors, so commands are always serviced.
  while (Serial.available()) {
    char c = Serial.read();
    if (c == '\n' || c == '\r') {
      if (inputBufferLen > 0) {
        inputBuffer[inputBufferLen] = '\0';
        handleCommand(inputBuffer);
        inputBufferLen = 0;
      }
    } else if (inputBufferLen < INPUT_BUFFER_MAX) {
      inputBuffer[inputBufferLen++] = c;
    } else {
      inputBufferLen = 0;  // oversized line — discard
      setLed(LED_ORANGE, true);
      transportSend("{\"error\":\"line too long\"}");
    }
  }

  runMachine();

#if defined(ARDUINO_ARCH_ESP32)
  // Wi-Fi housekeeping: process WebSocket frames, keep OTA alive, reconnect.
  if (wifiEnabled) {
    webSocket.loop();
    if (otaStarted) ArduinoOTA.handle();
    checkWifi();
  }
#endif
}

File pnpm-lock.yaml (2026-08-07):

lockfileVersion: '9.0'

settings:
  autoInstallPeers: true
  excludeLinksFromLockfile: false

overrides:
  protobufjs: '>=7.6.1'
  tar: '>=7.5.19'
  sharp: '>=0.35.3'
  kysely: '>=0.28.17'

importers:

  .:
    devDependencies:
      turbo:
        specifier: ^2.10.8
        version: 2.10.8
      vitest:
        specifier: ^4.1.10
        version: 4.1.10(@opentelemetry/api@1.9.0)(@types/node@22.19.11)(vite@6.4.3(@types/node@22.19.11)(jiti@2.6.1)(lightningcss@1.31.1)(tsx@4.21.0)(yaml@2.8.2))

  packages/server:
    dependencies:
      '@hono/node-server':
        specifier: ^2.0.12
        version: 2.0.12(hono@4.12.34)
      '@huggingface/transformers':
        specifier: ^3.8.1
        version: 3.8.1(@types/node@20.19.33)
      '@magic-vault/shared':
        specifier: workspace:*
        version: link:../shared
      dotenv:
        specifier: ^16.5.0
        version: 16.6.1
      drizzle-orm:
        specifier: ^0.45.2
        version: 0.45.2(@neondatabase/serverless@1.0.2)(@opentelemetry/api@1.9.0)(@types/pg@8.16.0)(pg@8.22.0)
      hono:
        specifier: ^4.12.4
        version: 4.12.34
      jose:
        specifier: ^6.1.3
        version: 6.1.3
      pg:
        specifier: ^8.13.0
        version: 8.22.0
      zod:
        specifier: ^4.3.6
        version: 4.3.6
    devDependencies:
      '@types/node':
        specifier: ^20
        version: 20.19.33
      '@types/pg':
        specifier: ^8.11.0
        version: 8.16.0
      drizzle-kit:
        specifier: ^0.31.9
        version: 0.31.9
      tsup:
        specifier: ^8.4.0
        version: 8.5.1(jiti@2.6.1)(postcss@8.5.6)(tsx@4.21.0)(typescript@5.9.3)(yaml@2.8.2)
      tsx:
        specifier: ^4.19.3
        version: 4.21.0
      typescript:
        specifier: ^5
        version: 5.9.3
      vitest:
        specifier: ^4.1.10
        version: 4.1.10(@opentelemetry/api@1.9.0)(@types/node@20.19.33)(vite@6.4.3(@types/node@20.19.33)(jiti@2.6.1)(lightningcss@1.31.1)(tsx@4.21.0)(yaml@2.8.2))

  packages/shared:
    devDependencies:
      typescript:
        specifier: ^5
        version: 5.9.3
      vitest:
        specifier: ^4.1.10
        version: 4.1.10(@opentelemetry/api@1.9.0)(@types/node@22.19.11)(vite@6.4.3(@types/node@22.19.11)(jiti@2.6.1)(lightningcss@1.31.1)(tsx@4.21.0)(yaml@2.8.2))

  packages/web:
    dependencies:
      '@base-ui/react':
        specifier: ^1.1.0
        version: 1.1.0(@types/react@19.2.14)(react-dom@19.2.3(react@19.2.3))(react@19.2.3)
      '@fontsource-variable/figtree':
        specifier: ^5.2.10
        version: 5.2.10
      '@fontsource-variable/geist-mono':
        specifier: ^5.2.7
        version: 5.2.7
      '@fontsource-variable/jetbrains-mono':
        specifier: ^5.2.8
        version: 5.2.8
      '@hookform/resolvers':
        specifier: ^5.2.2
        version: 5.2.2(react-hook-form@7.71.1(react@19.2.3))
      '@magic-vault/shared':
        specifier: workspace:*
        version: link:../shared
      '@tabler/icons-react':
        specifier: ^3.36.1
        version: 3.36.1(react@19.2.3)
      '@tanstack/react-query':
        specifier: ^5.90.21
        version: 5.90.21(react@19.2.3)
      class-variance-authority:
        specifier: ^0.7.1
        version: 0.7.1
      clsx:
        specifier: ^2.1.1
        version: 2.1.1
      next-themes:
        specifier: ^0.4.6
        version: 0.4.6(react-dom@19.2.3(react@19.2.3))(react@19.2.3)
      react:
        specifier: 19.2.3
        version: 19.2.3
      react-dom:
        specifier: 19.2.3
        version: 19.2.3(react@19.2.3)
      react-hook-form:
        specifier: ^7.71.1
        version: 7.71.1(react@19.2.3)
      react-router-dom:
        specifier: ^7.18.2
        version: 7.18.2(react-dom@19.2.3(react@19.2.3))(react@19.2.3)
      shadcn:
        specifier: ^4.16.1
        version: 4.16.1(typescript@5.9.3)
      sonner:
        specifier: ^2.0.7
        version: 2.0.7(react-dom@19.2.3(react@19.2.3))(react@19.2.3)
      tailwind-merge:
        specifier: ^3.4.0
        version: 3.4.0
      tw-animate-css:
        specifier: ^1.4.0
        version: 1.4.0
      vaul:
        specifier: ^1.1.2
        version: 1.1.2(@types/react-dom@19.2.3(@types/react@19.2.14))(@types/react@19.2.14)(react-dom@19.2.3(react@19.2.3))(react@19.2.3)
      zod:
        specifier: ^4.3.6
        version: 4.3.6
    devDependencies:
      '@tailwindcss/vite':
        specifier: ^4.2.1
        version: 4.2.1(vite@6.4.3(@types/node@20.19.33)(jiti@2.6.1)(lightningcss@1.31.1)(tsx@4.21.0)(yaml@2.8.2))
      '@types/node':
        specifier: ^20
        version: 20.19.33
      '@types/react':
        specifier: ^19
        version: 19.2.14
      '@types/react-dom':
        specifier: ^19
        version: 19.2.3(@types/react@19.2.14)
      '@types/w3c-web-serial':
        specifier: ^1.0.8
        version: 1.0.8
      '@vitejs/plugin-react':
        specifier: ^4.4.1
        version: 4.7.0(vite@6.4.3(@types/node@20.19.33)(jiti@2.6.1)(lightningcss@1.31.1)(tsx@4.21.0)(yaml@2.8.2))
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

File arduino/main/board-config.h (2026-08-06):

// Board abstraction for the DeckSift sorter firmware.
//
// One sketch (`main.ino`) runs on multiple controllers — the Arduino IDE /
// PlatformIO picks the right compile-time path below based on the selected
// board, so the same source flashes to an Uno R4 Minima, an ESP32-S3 (the
// DeckSift primary), an RP2040/Pico, an STM32, or a classic Uno/Nano.
//
// Compiling is NOT the same as being supported: the Uno R4 is the only
// board whose wiring has been physically commissioned. Read
// arduino/main/CONTROLLERS.md for per-board wiring (logic levels, pins,
// power) before building a non-Uno machine.
//
// Differences handled here:
//   - EEPROM persistence (real EEPROM vs flash emulation)
//   - I2C pins for the PCA9685
//   - interrupt-attach helper (digitalPinToInterrupt differs per core)
//   - IR/pin defaults (override with -D<MACRO>=n if your wiring differs)
//
// If you add a new board family, add its ARDUINO_ARCH_* branch here; the
// sketch itself needs no changes.
#pragma once

#include <EEPROM.h>
#include <Wire.h>

// ─── EEPROM init ─────────────────────────────────────────────────────────────
// AVR + Renesas (Uno R4) have hardware EEPROM: get/put work directly.
// ESP32 / RP2040 emulate EEPROM in flash and require begin(size) first.
#if defined(ARDUINO_ARCH_ESP32) || defined(ARDUINO_ARCH_RP2040)
  #define BOARD_EEPROM_BEGIN() EEPROM.begin(512)
  // Flash-emulated EEPROM stages writes in RAM — commit() flushes to flash.
  // Hardware-EEPROM boards (AVR/Renesas/STM32) persist immediately.
  #define BOARD_EEPROM_COMMIT() EEPROM.commit()
#else
  #define BOARD_EEPROM_BEGIN() ((void)0)
  #define BOARD_EEPROM_COMMIT() ((void)0)
#endif

// ─── I2C pins (PCA9685) ──────────────────────────────────────────────────────
// ESP32-S3 default Wire is GPIO 8 (SDA) / 9 (SCL) — explicit and overridable.
#if defined(ARDUINO_ARCH_ESP32)
  #ifndef I2C_SDA
    #define I2C_SDA 8
  #endif
  #ifndef I2C_SCL
    #define I2C_SCL 9
  #endif
  #define BOARD_I2C_BEGIN() Wire.begin(I2C_SDA, I2C_SCL)
#else
  #define BOARD_I2C_BEGIN() Wire.begin()
#endif

// ─── Interrupt attach ────────────────────────────────────────────────────────
// attachInterrupt is universal; only the pin-wrapping helper differs.
#if defined(ARDUINO_ARCH_STM32)
  #define BOARD_IR_ATTACH() attachInterrupt(IR_PIN_MODULE1, onModule1IR, CHANGE)
#else
  #define BOARD_IR_ATTACH() \
    attachInterrupt(digitalPinToInterrupt(IR_PIN_MODULE1), onModule1IR, CHANGE)
#endif

// ─── IR sensor pins (defaults) ───────────────────────────────────────────────
// Active-LOW: pin reads LOW when a card is present. All defaults are valid on
// Uno R4 (D2-D5), ESP32-S3 (GPIO 2-5) and RP2040. Override per machine.
#ifndef IR_PIN_MODULE1
  #define IR_PIN_MODULE1 2
#endif
#ifndef IR_PIN_MODULE2
  #define IR_PIN_MODULE2 3
#endif
#ifndef IR_PIN_MODULE3
  #define IR_PIN_MODULE3 4
#endif
#ifndef IR_PIN_HOPPER
  #define IR_PIN_HOPPER 5
#endif

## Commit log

2026-08-02 Add firmware build docs and custom plans
    Add the arduino build guide, serial protocol reference, and a custom folder documenting the fork workflow and the faster/more-robust rework plan.
2026-08-02 Correlate serial responses with command ids
    Firmware echoes an optional command id on every reply; the web app matches on it in sendBin/sendTest so asynchronous messages (jam alerts, boot ready) can never be misread as a command's response.
    [main.ino]
2026-08-02 Add typecheck, firmware compile, and CI checks
    Add a typecheck script for the web app, an arduino-cli compile script for the firmware, and CI running both on push, plus a changelog of our changes from upstream.
2026-08-02 Speed up card search with hydrated matches
    Encode the scan frame once, hydrate close matches server-side with a cached card lookup, and drop the per-match client round trips.
2026-08-02 Harden firmware with watchdog timing and EEPROM
    Interruptible delays with per-command watchdog budgets, jam detection on all modules mid-operation, EEPROM config persistence, protocol version handshake, ping liveness, and a fixed serial buffer.
    [main.ino]
2026-08-02 Consolidate serial commands and add bin capacity
    Correlate every command by id, share a single feed path, enforce per-bin capacity with session counts, dedupe captured images with a prune script, and add a device heartbeat.
2026-08-03 Fix firmware CI using a defunct action
    - arduino/arduino-cli-action returns 404 and failed every run
    - Switch to the official arduino/compile-sketches action
2026-08-03 Add heuristic holo detection that feeds training data
    - Score the warped scan crop for rainbow/specular foil signatures
    - Pre-fill the isFoil toggle; corrections persist as labeled samples
    - Thresholds are calibration starting points until the rig is built
2026-08-03 Add scan light, two-frame foil scan, and generic TCG adapter
    - Firmware: LED 5 scan light on PCA9685 ch14
    - Web: two-frame holo scan, skips second frame when clearly matte
    - Server: config-driven adapter factory + Yu-Gi-Oh!/Digimon configs
    - Docs: scan light wiring, protocol, top-20 TCG plan
    [main.ino]
2026-08-03 Add value-based binning and local runbook
    - Add price_usd_foil bin field; wire YGO card_prices into prices
    - Add start-web.cmd launcher; bring the web UI up on :5173
    - Document first-run setup, URLs, and known gaps in SETUP.md
2026-08-03 Add bundle mode and seed first-run setup
    Seed script creates games, collection, bin set, and a default 15/15/5/5
    bundle config; wire YGO/Digimon search adapters; add bundle config/run
    tables, API, web panel, and no-duplicate routing in the scan flow.
2026-08-03 Add build photos and credit the original MAULT project
    Download the original build photos into the repo (compressed from 22MB
    to 2.5MB) so the /build guide shows them offline, and add attribution
    to the upstream project in the landing/build footers, the open-source
    section, and the README.
2026-08-03 Add servo diagnostics and scan light control
    Add a commissioning panel that wiggles each servo so the operator can
    verify wiring and bin routing, plus a bin-route map and a scan-light
    toggle that was missing from the LED controls.
2026-08-03 Clear sync queue on GPU hang
    Auto-advancing into the next game after a DirectML device hang would run
    every remaining sync into guaranteed failure. Clear the queue so nothing
    starts until the server is restarted.
2026-08-03 Add card library browser
    New /app/library page with an art grid, game/rarity/set filters, name
    search, load-more pagination, and a card detail view, backed by a new
    GET /api/cards/library endpoint that reads art and rarity from the
    stored card data.
2026-08-03 Add bundle holo/duplicate toggles and bin capacity limits
    Bundle configs can now ignore holo detection entirely, filter targets by
    foil status, or allow duplicate cards. Bin max capacities are computed
    from the physical bin heights and average card thickness to prevent
    overflow, applied via a new script.
2026-08-03 Add per-bin status, empty/reset, and pause-on-overflow
    Bins now show live fill vs capacity with an Empty button that resumes a
    paused run; the machine pauses whenever a card has nowhere to go (full
    matched bin + full catch-all, or a full bundle destination/reject bin)
    instead of overflowing.
2026-08-04 Rebrand to DeckSift with custom license and credit restructure
    - LICENSE: DeckSift license (c) 2026 4holdingdirectlimited - free for
    personal use, commercial use by license; MAULT-derived portions stay
    MIT with the original Kenneth Bass notice
    - Rename all user-facing branding from Magic Vault/MAULT to DeckSift
    (landing, build guide, app nav, browser tab, Discord notifications)
    - Keep prominent credit for dishwasher-detergent's v1 Fusion design,
    build photos, and firmware base; credit DeckSift work to
    4holdingdirectlimited including the revised Bambu Lab print kit
    - Point Report an issue links at the DeckSift repo
    - Update README, custom docs, and product strategy for the new
    lic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
2026-08-04 Give the front end a professional DeckSift makeover
    - New DeckSift brand mark (layered deck glyph) replaces the inherited
    MAULT pig logo across landing, build guide, and app nav
    - Rebuilt landing hero as a live-machine console: status chips, animated
    scan beam over a card, bin routing strip, and a stat bar (TCGs, card
    library, bins, offline)
    - Added brand utilities to the design system: grid backdrop, gradient
    text, primary glow, scan-beam animation
    - Polished feature cards (gradient icon tiles, hover lift), how-it-works
    pipeline (numbered steps with connectors), and open-source cards
    - Landing nav and footers tightened; app nav now uses the DeckSift mark
    - Point fork/issue links a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
2026-08-04 Make app logo a home link and finish the interface audit
    - App sidebar DeckSift mark now links to the landing page (home) with
    a 'Home' tooltip instead of being a dead element
    - Replace the last remaining pig logo in the build guide nav with the
    DeckSift mark and align the header with the landing page
    - Audit of every link and anchor across the interface: landing nav and
    footer (#features / #how-it-works / #open-source), build guide
    (#parts / #wiring / #assembly), app shell routes, and the status
    footer sync link all resolve correctly
    - No remaining stale branding: all MAULT references are upstream
    attribution, fork/issue links point at 4holdingdirectlimited/DeckSift
2026-08-04 Show live game and card-library counts on the landing page
    The hero stat bar previously hardcoded '5 TCGs supported' and
    '100k+ cards'. It now fetches the real numbers on load - supported
    games from the sync-source registry and the total synced card count
    summed across games - so both stay accurate as new TCGs are added
    and the library grows. A placeholder shows until the data loads.
2026-08-04 Fix game-select labels and bundle delete identifier mismatch
    - Game dropdowns (new collection dialog, first-run dialog, collection
    switcher) now pass an explicit label to each SelectItem. Base UI
    otherwise derives the trigger text from measuring the item's rendered
    content, which can fall back to the raw value (the game's UUID) when
    that measurement races - the 'bunch of letters and numbers' seen when
    picking Pokemon etc. The trigger now always shows the game name
    - Bundle inventory delete dialog: the confirmation previously demanded
    the full 36-char run guid while the row showed only the SKU or first
    8 chars. It now asks you to type exactly the identifier shown on the
    row, s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
2026-08-04 Add review queue, set-completeness toasts, and non-blocking firmware
    Review queue (web):
    - Low-confidence scans (distance >= 0.18 or close alternatives) now pause
    with a Sort it / Skip panel instead of auto-routing; toggle in the
    scanner menu, on by default
    - ScannerStatus gains a 'review' state
    Set completeness (web):
    - Per-scan toast counting unique cards owned in the card's set vs the
    set's library total, fired on milestones to avoid spam
    Firmware (non-blocking state machine + interrupt IR):
    - Feed/route/test/clear are now phases of a runMachine() state machine
    driven from loop(): serial stays responsive mid-operation, cancel
    aborts any phase, jam alerts abort immediately, bus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
    [main.ino]
2026-08-05 Integrate useful upstream changes
    - Add TTL + in-flight dedupe cache for all five card-search adapters
    - Add Min. match % slider filter; paginate card grid (96/page) and drop
    framer-motion from the scan render path for faster UI during runs
    - Add game-switch alert, fix select labels showing raw values
    - Bump scan settle delay 300->500ms; add wiring diagram + reorder build docs
2026-08-05 Add configurable match thresholds and alert dismissal
    - Review-below and auto-reject-below sliders in Scanner menu replace the
    hardcoded 82% review pause; auto-reject routes to catch-all without pausing
    - Game-switch alert remembers dismissals per game
    - Fix Tailwind v4 bg-gradient-to-br lint
2026-08-05 Update repo docs and CI to match current project
    - custom/README: drop the deleted master mirror workflow, note upstream remote
    workflow, mark non-blocking state machine delivered (item 49)
    - Mark Bambu Lab print kit as planned (not yet in repo) in README, BUILD,
    CHANGES, and add a PLAN.md section so the claim is grounded
    - CI: run checks on custom only (master branch no longer exists)
    - README structure: list all custom/ docs
2026-08-05 Add scan-rate telemetry and reliability improvements
    - Live scans/min (rolling 60s) + last-scan timing in stats for tuning
    - Review/auto-reject thresholds now per-game, reload on collection switch
    - Paginate the monitor grid (96/page) for large live sessions
    - Retry feeder once on timeout before pausing the line
2026-08-05 Add decksift.local access and software-only speed batch
    - decksift.local over HTTPS: mkcert script, hosts doc, relative API base,
    multi-origin CORS, Vite host+preview proxy
    - Pipelining step 1: firmware queues a feed sent while busy (reply when it
    completes) + cancelFeed; web requests the next card up front
    - Runtime-tunable route delays: DELAY_* -> EEPROM TimingConfig (v2) +
    setTimingConfig + Calibrate-page panel
    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
2026-08-05 Remap LEDs to status lamps, add calibration backup, review upstream
    - Scan light moves to LED 1 (ch0); LED 2/3/4 = green/red/orange status
    lamps driven by firmware + mirrored in the browser (MachineLeds)
    - Calibrate page: Export/Import full calibration JSON (modules+feeder+timing)
    so a replaced Arduino is reloaded in minutes; firmware getTimingConfig
    - Adopt upstream's safe small-travel servo defaults + sent-command logging;
    copy 3d model LICENSE (CC BY-NC-SA) + upstream files to files-for-review;
    add card_sorter_decksift.3mf alongside the original
    - decksift.local hosts helper + working HTTPS access
    [card_sorter_decksift.3mf]
2026-08-05 Make firmware universal with ESP32-S3 as primary board
    - New board-config.h abstracts EEPROM init, I2C pins, interrupt attach, IR pins
    - One sketch compiles for Uno R4 + ESP32-S3 (verified), RP2040 + STM32 paths
    - Bounded serial wait so native-USB boards can't hang headless boots
    - CI now compiles both boards; docs + build guide updated for the board table
2026-08-06 Verify RP2040/STM32 builds, add ESP32-S3 flash docs, tidy repo
    - RP2040 Pico + STM32 GenF4 compile verified (3%/4% flash)
    - ESP32-S3 Tools-menu settings table + platformio.ini for Web Serial
    - Print files are the repo 3MFs (card_sorter_decksift.3mf is the kit)
    - files for review/ moved out of the repo to the desktop, gitignored
2026-08-06 Rebase upstream PR branches onto current master; all mergeable
    - pr/fw-robustness, pr/fw-config, pr/fw-state-machine rebased onto
    upstream/master (61c67e7) with our exact firmware content - all three PRs
    (#4/#5/#6) are now MERGEABLE
    - PR #5 title/body updated to the LED 1 scan light
2026-08-06 Make the landing page accurate: local hero art and honest stats
    - Hero card art now comes from the local library (/api/cards/random) instead
    of api.scryfall.com - no external calls anywhere in the web app
    - Stats: 5 TCGs (was MTG-only '4 rarities'), ~1s identify (was <1s)
    - Print-kit wording points at the repo's card_sorter_decksift.3mf
    - Community card attributes the Discord to the original MAULT project
2026-08-06 Document per-board support honestly: CONTROLLERS.md + wiring deltas
    - New arduino/main/CONTROLLERS.md: logic levels (3.3V boards are NOT 5V
    tolerant), IR-sensor wiring, pin map table with recommended ESP32-S3 pins,
    power, boot/serial notes, and honest verification status per board
    - Main README: stack + Hardware sections now list ESP32-S3 as primary, fix
    stale LED 5/ch14 -> LED 1/ch0, link the controllers doc
    - arduino README board table: compile vs commissioned status; warning banner
    - In-app build wiring page: 3.3V/5V logic warning for non-Uno boards
    - board-config.h comment: compiling != supported
    [board-config.h]
2026-08-06 Validate ESP32-S3 on hardware, fix EEPROM commit, add printable BOM
    - Real-device test caught a portability bug: ESP32/RP2040 EEPROM needs
    commit() to reach flash - BOARD_EEPROM_COMMIT() added, verified persisting
    - ESP32-S3 (CH343 dev board): boot, protocol, LED, timing, EEPROM all pass
    - Document the two ESP32-S3 serial paths (bridge vs native USB); correct
    the earlier unconditional 'enable USB CDC' advice
    - New arduino/main/BOM.txt printable shopping list
    [board-config.h, main.ino]
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2026-08-06 Finalize ESP32 OTA testing and unify LED handling
    - onWifiConnected() shared by setup() and checkWifi(); WiFi.mode() must
    run before webSocket.begin() on core 3.x (boot-loop fix, verified over
    live OTA on hardware)
    - LED command unified to 1-4 via setLed(); drop the dead LED 5/ch14 branch
    - Docs: CHANGES item 59 marks OTA verified; README partition/OTA guidance
    corrected; SERIAL_PROTOCOL error table fixed; PLAN scan-light + status
    [main.ino]
2026-08-06 Remove dead web code and harden dev tooling
    - Drop unused deps (framer-motion, idb, input-otp) and four orphan
    components; remove the unused geist-mono font import
    - Fix react-hooks lint warnings and Tailwind v4 class shorthands
    - arduino-compile.sh now covers ESP32-S3 like CI; start-server.cmd uses
    the version-agnostic tsx shim
    - UPSTREAM_PRS.md points at upstream-pr-N.md instead of duplicating bodies
    [pnpm-lock.yaml]
2026-08-06 Make setup tooling portable for fresh clones
    - .local state (postgres, certs, backups) now resolves next to the repo
    instead of a hardcoded path; DECKSIFT_LOCAL_DIR overrides the location
    - start-server.cmd / start-web.cmd derive the repo root from %~dp0
    - Docs: relative start commands, the .local convention, corrected
    firmware-flash section (ESP32-S3 primary, WebSockets library) and
    apply-bin-capacities invocation
    - Add node/pnpm engines and clarify the Node 20.6+ prerequisite
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

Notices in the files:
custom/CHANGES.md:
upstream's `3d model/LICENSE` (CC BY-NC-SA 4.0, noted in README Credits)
